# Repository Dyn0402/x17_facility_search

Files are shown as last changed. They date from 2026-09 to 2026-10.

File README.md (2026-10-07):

# x17_facility_search

Where else could the n_TOF X17 apparatus make an X17 measurement?

The MX17 setup (a ³He target, four arms of Micromegas TPCs, SiPM and plastic
trigger scintillators, and a DREAM readout) ran at CERN n_TOF in 2026 to look for
the X17 boson in n + ³He → ⁴He\* → ⁴He + e⁺e⁻. This repo asks which other neutron
facilities could host the same hardware, possibly with a new target and modest
upgrades, and how far each one could reach in X17/IPC.

The studies start analytic (Highland scattering budgets, rate scaling, published
beam data). Each one is then checked against Geant4 campaigns of the full
apparatus, run on lxplus/HTCondor.

## Facilities

| facility | beam | status | where |
|---|---|---|---|
| **ILL Grenoble, PF1B** (also FIPPS) | Continuous cold reactor beam, ~10¹⁰ absorbed n/s, thermal capture at rest (E\* = 20.58 MeV) | **Most developed.** Full Geant4 campaign done. One unpolarised 50-day cycle reaches X17/IPC(M1) ≈ 1.2×10⁻² at 3σ with n_TOF hardware, Micromegas-segment cuts and a CFRP end cap. That is ~7× short of ATOMKI's ⁸Be level, and ×3–4 short even with zero background. Current work: rate walls, flight tube, window choice, polarised option. | [`ill/`](ill/README.md) |
| **LNL Legnaro, AN2000 / CN** | DC ~1 MeV protons on a thin ⁷Li film, the ATOMKI reaction ⁷Li(p,e⁺e⁻)⁸Be at the 18.15 MeV resonance; up to 1 µA (AN2000) / ~4 µA (CN, also pulsed) | **Started 2026-10-07.** Facility, reaction and targets researched; pre-Geant4 estimate: the ATOMKI ratio at 3σ in ~2 weeks at 1 µA with the n_TOF hardware (~1 week with calorimetry), IPC-limited once the MM tracks veto cosmics. LNL's own ⁸Be spectrometer already ran there in 2023–24. Next: slides, Geant4 target region. | [`lnl/`](lnl/README.md) |
| **GANIL / SPIRAL-2 NFS** (Caen) | Pulsed fast neutrons, d+Be or quasi-monoenergetic, 1–40 MeV | Plan plus a literature beam reference. The open issue is the sub-2 MeV flux the physics wants: it is unmeasured. Options include a lower deuteron energy, D(d,n), and ⁷Li(p,n) near threshold. | [`docs/PLAN_GANIL_NFS.md`](docs/PLAN_GANIL_NFS.md), [`ganil_nfs/`](ganil_nfs/README.md) |
| FRM II MEPHISTO, ESS ANNI, NIST, HFIR | Cold beams | Mentioned only (`ill/FACILITY.md`, "Alternatives") | — |

## Layout

| directory | what it is |
|---|---|
| [`ill/`](ill/README.md) | ILL feasibility: facility record (`FACILITY.md`), analytic projection (`ill_rates.py`), the Geant4 answer (`FEASIBILITY_SIM.md`), polarised option (`POLARISED.md`), lxplus drivers (`sim/lxplus/`), slide deck (`deck/build_deck.py`) |
| [`lnl/`](lnl/README.md) | LNL feasibility for the ⁸Be search: facility (`FACILITY.md`), reaction (`PHYSICS.md`), lithium targets (`TARGETS.md`), the rate/acceptance/reach model (`lnl_rates.py` → `ESTIMATES.md`), and the Geant4 plan (`GEANT_PREP.md`) |
| [`ganil_nfs/`](ganil_nfs/README.md) | NFS beam reference: spectra, converters, timing, backgrounds, rates for our geometry, with sources (`refs/`) and a beam model (`nfs_beam.py`) |
| `docs/` | The GANIL/NFS plan and its anchor calculations (`anchor_kinematics.py`, `anchor_numbers.py`, `anchor_vessel.py`) |
| [`trigger_scint/`](trigger_scint/README.md) | Facility-independent: fixing the trigger-scintillator acceptance. The as-built stack accepts 2.3 % of X17 pairs; four ~75 cm plastics give ~14 %. Includes big-slab backgrounds at the ILL. |
| [`he4_bag/`](he4_bag/README.md) | A ⁴He bag / flight tube against air ¹⁴N, and the ³He-tight cell skin (12 µm PET + 6–7 µm Al) |
| `vessel_design/` | Parametric CAD of the 1 bar mylar-wrap, carbon-rod-cage ³He cell (STEP/STL/FreeCAD in `out/`) |
| `3he_material_budget/` | Early Highland material-budget script for the ³He target |
| `HANDOFF.md` | Running session handoffs, newest first: what is in flight on lxplus and the next steps |

## Running

Python 3 with numpy, pandas and matplotlib. The repo has no venv of its own; use
the nTof_x17 one:

```bash
~/PycharmProjects/nTof_x17/.venv/Scripts/python.exe ill/ill_rates.py --write   # Windows
~/PycharmProjects/nTof_x17/.venv/bin/python        ill/ill_rates.py --write   # Linux
```

Each subdirectory README lists its commands and outputs. Geant4 runs only on
lxplus (see `CLAUDE.md` for paths). The small analysis outputs are copied back
into `*/sim/` and `*/out/`; the full outputs stay on EOS.

## Related repositories

- **`MX17_Full_Geant`** (GitHub `Dyn0402/MX17_Full_Geant`, `~/CLionProjects/`):
  the full Geant4 simulation of the n_TOF apparatus. The `ill` and
  `trigger_plastics` branches carry the facility-search geometry.
- **`MX17_Geant`** (`~/CLionProjects/MX17_Geant`): the Micromegas module Geant4
  sim and the one shared module geometry (`shared/MX17ModuleGeometry.hh`).
- **`nTof_x17`** (`~/PycharmProjects/nTof_x17`): the n_TOF data analysis, the fast
  MC and the measured detector response.
- **`nTof_x17_DAQ`**: DREAM DAQ characterisation (dead time, rate limits).
- **`dylan-cern-site`**: publishes the notes and decks
  (`dylan-neff.web.cern.ch/notes/`).

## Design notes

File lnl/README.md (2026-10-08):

# LNL (Legnaro): the ATOMKI ⁸Be search with the MX17 apparatus

Started 2026-10-07. Could the n_TOF X17 apparatus repeat the ATOMKI measurement,
⁷Li(p,e⁺e⁻)⁸Be at the 18.15 MeV resonance, on a low-energy proton beam at INFN
Laboratori Nazionali di Legnaro? What is the beam, what does a lithium target look
like, and how far would we get before any Geant4?

## Read this first: the Geant4 result (2026-10-08, `FEASIBILITY_SIM.md`)

Days to show the ATOMKI ratio R = 5.8×10⁻⁶ at **3σ**, Li₂O 300 µg/cm² at 1.10 MeV, **1 µA**,
data-like selection on Geant4 L1–L6:

| hardware | counting / template fit | at CN 4 µA |
|---|---|---|
| **n_TOF as built** (LS read out), with 3° MM segments **or** a 0.3 ns TOF veto | **15 / 22 d** | 4 / 6 d |
| as built, LS dead | 19 / 25 d | 5 / 6 d |
| **4 big plastics 75×75×5 cm + all 20 SiPM bars** (trigger_scint, ~€90–140k) | **1.2 / 1.6 d** | **0.3 / 0.4 d** |

- **Signal acceptance as built: 3.3 % pair-tag** (2.4× below the toy × `EPS_REST`). The
  two 20×30 cm plastics are the bottleneck; the big plastics give 23 %.
- **E_sum separates the γ₁ (15 MeV) IPC.** It is removed as built (with LS) and with the
  big plastics; with the LS off it is not.
- **Cosmics are the one danger:**
  - 8×10⁴/day in 125–155° at trigger level, against ~120 IPC/day after cuts;
  - the measured chambers' 15° segments do not stop them;
  - an upper E_sum edge (muons leave 20–35 MeV), 3° segments or TOF do.
- EPC, accidentals, DREAM dead time, the 478 keV line: negligible.
- Keep the **CFRP chamber and a low-Z backing**. Al 1 mm doubles σ_θ (5° → 12°).
- The E0 6.05 MeV calibration line is invisible to the n_TOF trigger. Calibrate on 441 keV.

The pre-Geant4 estimate below is kept for the record. Its detector factors are superseded.

## Bottom line (pre-Geant4, good to ~×2; detector part superseded above)

- **The beam is easy.**
  - AN2000: 0.2–2 MV, up to 1 µA H⁺, self-service.
  - CN: 0.8–5.5 MV, 1 µA at 0.8–2 MeV in the beam sheet; ~4 µA authorised; also a
    3 MHz, < 2 ns **pulsed** mode.
  - Both cover 441–1225 keV. There are **no neutrons below the 1.88 MeV ⁷Li(p,n)
    threshold**, so radiation protection does not cap the current.
  - Access is through the LNL PAC (yearly, autumn) `FACILITY.md`.
- **LNL already did this.**
  - The LNL-INFN pair spectrometer (Marchi, Góngora-Servín, Tagnani *et al.*;
    ATOMKI-style plastic ΔE–E clovers) ran on **AN2000 in 2023–24**: LiF targets,
    441 keV and 1.03 MeV, ~800 nA, ~790 h.
  - It is still unpublished as of Oct 2026.
  - They are the first people to talk to.
- **The physics.**
  - A ~1 MeV proton is captured on ⁷Li, making ⁸Be\* at E\* = 17.255 + 0.875·E_p MeV.
  - It does so mostly via two M1 resonances (441 keV → 17.64; 1030 keV → 18.15),
    on top of a flat **E1 direct capture that is ~half of the γ₀ at 1.03–1.10 MeV**.
  - X17 pairs pile up above an edge at **~134–138°**.
  - Details in `PHYSICS.md`.
- **Who has looked so far.**
  - ATOMKI: 6.8σ in 2016; also off-resonance in 2022.
  - Hanoi: > 4σ in 2024.
  - **MEG II: nothing**, R(18.1) < 1.2×10⁻⁵ (2025).
  - MEG II members showed in **Sept 2026** that cosmic rays make a 140° bump in
    ATOMKI-type spectrometers.
- **Targets** (`TARGETS.md`).
  - A few-hundred-nm film of LiF or Li₂O (or Li metal, or sputtered LiPON) on a
    10–25 µm Al/C/Cu foil, in a thin carbon-fibre chamber.
  - Keep it thin (≲ 300 µg/cm² ≈ 60 keV), so the beam never slows into the 50×
    stronger 441 keV resonance. ATOMKI's 2016 metallic-Li targets did exactly that.
  - Use **boron-free** Li: ¹¹B(p,γ) puts 16–17 MeV γ in the window.
- **Rates.** At ATOMKI conditions (Li₂O 300 µg/cm², 1.10 MeV, 1 µA):
  - ~1.9×10³ γ₀/s and ~7 IPC/s into 4π;
  - **~900 X17/day** at the ATOMKI ratio R = 5.8×10⁻⁶.
- **Our apparatus.**
  - The four big Micromegas arms see the 140° region through opposite arms, at
    **~40 % geometric acceptance** (ATOMKI's spectrometer: ~2.5 %).
  - After the as-built trigger stack, ~46 X17/day are accepted at 1 µA, against
    ~1.1k (γ₀) + 2.1k (γ₁) IPC and ~200 cosmics per day in 125–155°.
- **Reach.** Days to show the ATOMKI ratio at **3σ / 5σ**, 1 µA:

  | stack | days, 3σ / 5σ |
  |---|---|
  | as built (cannot separate 15 from 18 MeV) | **~15 / ~40** |
  | with calorimetry | **~6 / ~16** |

  - ×4 faster at CN's 4 µA.
  - MEG II's 90 % limit is crossed in ~¼ of that time.
  - Off-resonance points (0.8, 1.225 MeV) are 3–4× slower.
  - Full table in `ESTIMATES.md`.
- **The MM tracking is the decisive advantage.**
  - With segment + collinearity cuts (ILL §10), cosmics drop below the IPC.
  - Without them the reach is 2.5× worse and cosmics dominate, which is the failure
    mode the 2026 paper attributes to ATOMKI.
  - CN's pulsed beam and the point-vertex cut add margin.
- **For comparison:** this is a much easier experiment for MX17 than the ILL thermal
  search (`../ill`). It has ~3× the accepted signal per day and no neutron
  backgrounds, and it is the measurement that decides the claim.

**Biggest unknowns, and what replaces them** (`GEANT_PREP.md`):
1. the trigger × E_sum × reconstruction factor carried from the ILL (`EPS_REST` = 0.14);
2. whether the stack can separate 15 MeV from 18 MeV pairs;
3. cosmics in the LNL hall;
4. hall space at AN2000/CN.

## Files

| file | what it is |
|---|---|
| `FACILITY.md` | LNL: AN2000 and CN specs, current/energy limits, pulsed beam, lines, schedule, PAC route and contacts, the local ⁸Be group, open questions **(ask)** |
| `PHYSICS.md` | The reaction step by step, ⁸Be levels and widths, direct capture, IPC, X17 kinematics vs E_p, every measurement so far (ATOMKI 2016/2022, Hanoi, MEG II, LNL, MEG-2026 cosmics), what a new measurement must get right |
| `TARGETS.md` | What a Li target is and how it is made; LiF vs Li₂O vs Li vs LiPON; contaminant reactions (¹⁹F, ¹¹B, ²⁷Al…); backings, heat, dose; recommendation |
| `ESTIMATES.md` | The pre-Geant4 numbers: 4π rates per configuration, toy acceptance, reach and days-to-significance, assumption table |
| `FEASIBILITY_SIM.md` | **The Geant4 result** (L1–L6, big plastics, 20-bar readout): acceptance, E_sum, cosmics, EPC, accidentals, DAQ, material, reach |
| `sim/lnl_geant.py` | The Geant4 analysis → `out/geant/` (tables + figures); `sim/fetch_sel.sh` copies the merged tables from EOS; `sim/lxplus/` = condor reduce/merge (`lnl_pipe.sh`) |
| `GEANT_PREP.md` | What to build in MX17_Full_Geant (branch `lnl` from `ill_ring`), the run list L0–L6, decisions needed first |
| `lnl_rates.py` | The model: kinematics, Zahnow σ split into resonances + direct capture, PSTAR stopping, thin/thick yields, Born IPC (from nTof_x17 `ipc_born`), four-arm toy acceptance, counting reach |
| `out/*.csv`, `out/figures/` | `kinematics`, `excitation`, `yields`, `ipc_alpha`, `acceptance(_hist)`, `reach`; figures with their CSVs; `viewer_yield_grid.json` (the `Y` table in the 3D viewer) |
| `data/exfor_A0639_Zahnow1995.txt` | ⁷Li(p,γ)⁸Be S-factors, γ₀ and γ₀+γ₁, 98–1500 keV (EXFOR) |
| `data/pstar_stopping.csv` | NIST PSTAR proton stopping for LiF, Teflon, C, O, Al, Be, Cu, Ti, Mo, W, Au, Ag, Kapton, Mylar, air, H |
| `viz/lnl_setup_3d.html` | 3D view to scale: MX17 arms + trigger stack around the Li target and chamber, vs the LNL 2023–24 clovers and ATOMKI 2016; live rates per machine/energy/film from `lnl_rates.py`; illustrative X17 / IPC / cosmic events |
| `refs/*.txt` | Text extractions of every source (PDFs in `refs/pdf/`, not committed) |

```bash
PY=~/PycharmProjects/nTof_x17/.venv/Scripts/python.exe   # Linux: .venv/bin/python
$PY lnl/lnl_rates.py          # tables + CHECK lines + figures (~3 min)
$PY lnl/lnl_rates.py --quick  # tables only, small MC
```

`lnl_rates.py` imports `sept26_prelim_analysis/ipc_born.py` from the nTof_x17 checkout
(`$NTOF_X17`, default `~/PycharmProjects/nTof_x17`). The CHECK lines compare it with
Tilley (σ at 441 keV, branching), Rose (IPC α), MEG II's own normalisation, and a
measured thick-target yield.

## Status and next steps (2026-10-08)

1. **Slides: done.** `deck/build_deck.py` → `out/lnl-x17-feasibility.html`, live at
   dylan-neff.web.cern.ch/notes/lnl-x17-feasibility.html and linked from `/facilities/lnl.html`.
   Rebuild after any change to `lnl_rates.py` outputs, then republish with `add-note.py … --force --deploy`.
   Slides 15–33 are a "basics" appendix (beam, targets, chamber, the physics channel incl. where the
   beam energy goes (E*, C1a–c), glossary),
   built by `deck/appendix.py` from `appendix_calc.py` → `out/appendix/*.csv` (2026-10-08). Its
   chamber-wall resolutions other than the three Geant4 walls are a Highland model fitted to L5
   (an analytic stand-in).
2. **Geant4: done** (2026-10-08), `FEASIBILITY_SIM.md`. Open: the SiPM-wall time
   resolution and whether the LS can be read (ask); the Zhang–Miller IPC shapes.
3. **Emails** (not sent). Anna Selva / pacbeams@lnl.infn.it (machines, hall, next PAC);
   T. Marchi (their 2023–24 data, the Góngora-Servín thesis, collaboration); our own
   collaboration (the ATOMKI demonstrator test).

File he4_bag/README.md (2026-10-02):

# A ⁴He bag around the ILL ³He target

2026-10-02. The question: air ¹⁴N is a significant background at the ILL
(`../ill/`). Would a ⁴He balloon around the ³He cell remove it? What would it
do to lepton scattering and to ³He loss through the cell wall?

It also covers the follow-up: the ³He leak rate turned out to be large, so
how do we make the cell tight without adding background or e⁺e⁻ scattering,
and should it stay at 1 bar?

Everything here is analytic. It is calibrated against the ILL Geant4 campaign
where that campaign has a number: the ¹⁴N(n,γ) rate on the air path matches
V0 to 1 %.

| file | what it is |
|---|---|
| `he4_bag.py` | All the arithmetic. §1 neutrons in air vs ⁴He; §2 Highland scattering on the cell → Micromegas chord; §3 ³He permeation of G1–G6, in air or in a ⁴He bag; §4 alternative skins for the 1 bar cell; §5 leak budget of seals and bonds; §6 choosing the foil (metal, gauge, scattering budget, strength) |
| `make_he4_bag_deck.py` | The slide note, built with `dylan-cern-site/scripts/slidedoc.py`. It reads `he4_bag.py` directly, so its numbers and titles follow the model |
| `out/neutrons.csv` | Captures and scattering per beam neutron on the 30 cm path, for air and for He at several air fractions |
| `out/leptons.csv` | θ₀ per leg vs lepton KE: air, ⁴He, ⁴He + bag foil |
| `out/permeation_bif{1,10}.csv` | Per cell: ³He loss per day and per cycle, cost, τ, ⁴He and air inflow, sealed-cell dilution |
| `out/he4_flush_bif1.csv` | Fresh-³He flow that holds ⁴He < 5 % in a cell sitting in the bag |
| `out/skins.csv` | Skin options for the G1 geometry: x/X₀, θ₀ at 6.3 MeV, loss range, barrel captures, hardest γ line |
| `out/seals.csv` | Leak budget: O-rings, epoxy bonds, foil pinholes, bare barrel |
| `out/metals.csv` | §6a: barrier metals (Al, Be, Mg, Zr, Cu, Pb) at their thinnest foil on 12 µm PET |
| `out/foil_gauge.csv` | §6b: Al gauge 6–25 µm: θ₀, captures, typical pinholes, barrel loss |
| `out/chord_budget.csv`, `out/chord_ladder.csv` | §6c: x/X₀ per layer of a lepton leg; θ₀ as the big layers are replaced |
| `out/hoop.csv` | §6d: membrane stress at 10 / 30 / 50 / 1000 mbar |
| `out/figures/he4_bag.png` (+ `.csv`) | Summary figure: ¹⁴N vs bag purity, and the sealed-cell ³He decay |
| `out/he4_bag_deck.html` | The slide note, live at <https://dylan-neff.web.cern.ch/notes/ill-he4-bag-3he-leak.html> |

```bash
python3 he4_bag/he4_bag.py              # tables -> he4_bag/out/
python3 he4_bag/make_he4_bag_deck.py    # -> he4_bag/out/he4_bag_deck.html
python3 ~/PycharmProjects/dylan-cern-site/scripts/add-note.py he4_bag/out/he4_bag_deck.html \
        --slug ill-he4-bag-3he-leak --force --deploy
```

Inputs from `../ill/`:
- `out/h113_spectrum.csv`;
- the V0 and C1 rates quoted in `SIM_STATUS.md` and `FEASIBILITY_SIM.md`;
- `sim/analysis_v3/contract_ladders.csv` (wall captures).

It needs numpy, pandas, scipy and matplotlib. The figure uses
`ill/figstyle.py`.

**Assumptions to replace with measurements:**
- He permeability: PET ~1 barrer (literature, ~2×); Kapton 1 barrer
  (placeholder, sources differ ~10×). N₂ 0.006 and O₂ 0.03 barrer in PET.
- ³He permeates 10 % faster than ⁴He.
- Metallisation barrier factor (BIF): 1–10, unmeasured.
- Foil pinholes: ~50/m² at 9 µm.
- Viton O-rings: Parker rule, 9 barrer. Epoxy: 5 barrer.
- ³He at 2500 €/L(STP).
- ~10⁻⁴ barrel crossings per beam neutron.

## Bottom line

- **⁴He gives no ¹⁴N-like background.** It captures no neutrons at all,
  because there is no bound ⁵He. It also scatters neutrons ~13× less than air.
- **The air that matters is the 300 mm of open beam path** between the
  collimator aperture and the Be window, not the air around the cell.
  - The analytic ¹⁴N(n,γ) rate on that path is 2.54 × 10⁻⁴ per beam neutron.
    Geant4 V0 gives 2.5 × 10⁻⁴ (ratio 1.01).
  - All air in C1 gives 2.7 × 10⁻⁴/n. So ~90 % of the ¹⁴N(n,γ) is the
    direct beam in that path. The other ~10 % is scattered neutrons captured
    in air around the detector. (This split is inferred by comparing two runs;
    it was not tallied directly.)
- **So the sensible version of the idea is a He-filled (or evacuated) flight
  tube** from the aperture to the Be window, sealed onto the cell flange. It
  removes:
  - ~90 % of the air ¹⁴N(n,γ);
  - the 0.6 % ¹⁴N(n,p) loss;
  - the ~2 % of beam scattered in air.

  The He only has to be ~99 % clean: the remaining ¹⁴N scales with the air
  fraction (1 % air → 2.5 × 10⁻⁶/n, a 100× reduction). This is standard
  beamline practice and was already on the list in `FEASIBILITY_SIM.md` §6.4.
- **A balloon around the cell and detector is not worth it.**
  - What it would add: the remaining ~10 % of air captures, and ~20 % less
    lepton scattering, which is worth < 2 % in reach.
  - What it would cost: it floods a mylar cell with ⁴He (see below). He would
    also permeate the Micromegas entrance windows into their gas, and HV breaks
    down far more easily in He than in air.
- **Permeation: the bag neither slows nor speeds the ³He loss**, because the
  ³He partial pressure outside is ~0 in air and in ⁴He alike. **It does hurt
  through what comes in.** ⁴He enters the cell ~90× faster than N₂ + O₂ do
  from air (mylar), or ~20× faster (Kapton). A sealed cell in the bag slowly
  becomes ⁴He.
- **Side finding that matters more:** bare 12 µm mylar (G1) loses ~0.45 L(STP)
  of ³He per day. That is a 3.4-day time constant, ~22 L per 50-day cycle, of
  order 50 k€. The source figure is a literature PET He permeability of
  ~1 barrer, uncertain by ~2×. Either the metallisation gives a measured ≳10×
  barrier, or G1 needs a feed system and a budget for the loss. This sharpens
  the "G1 if permeation is manageable" caveat in `FEASIBILITY_SIM.md` §5.

## 1. Neutrons (H113 beam, mean λ 4.87 Å)

Cross sections: thermal values (Sears/NIST), scaled as 1/v for absorption. The
free-gas correction is applied for scattering.

| gas on the 30 cm path | ¹⁴N(n,γ) 10.8 MeV /n | ¹⁴N(n,p) /n | ⁴⁰Ar(n,γ) /n | scattered |
|---|---|---|---|---|
| air | 2.5e-4 | 5.8e-3 | 1.3e-5 | 1.6 % (G4: ~2 %) |
| He + 5 % air | 1.3e-5 | 2.9e-4 | 6e-7 | 0.19 % |
| He + 1 % air | 2.5e-6 | 5.8e-5 | 1e-7 | 0.13 % |
| pure ⁴He | 0 | 0 | 0 | 0.12 % |

- With the air path in He, the hardest remaining single-capture lines near the
  beam come from the Be window (1.4 × 10⁻⁴/n, 6.8 MeV) and the Al ring
  (1.5–1.9 × 10⁻⁴/n, 7.7 MeV). Both are well below the Esum > 13 MeV cut.
  - ¹⁴N survives in the Kapton walls (G3–G6) and in the air around the
    detector, so the 10.83 MeV endpoint does not go away. Its rate drops ~10×.
- Use mylar, not Kapton, for any tube window: Kapton contains N.
- The 2 % of the beam scattered in air may also feed some of the captures in
  the detector materials (~1 × 10⁻³/n), which dominate the Micromegas rate.
  Analytics cannot settle that. **One Geant4 rerun would:** C1 on G1 with the
  flight path set to G4_He. It would also give the change in Micromegas rate
  and in the accidental Esum tail.

## 2. Lepton scattering

Highland θ₀ per leg, for the G1 skin, the Micromegas entrance and 16 cm of
gas. The energies are the p10/50/90 of the softer X17 lepton and the median of
the harder one.

| KE [MeV] | air | ⁴He, bag sealed on the MM windows | ⁴He + 25 µm mylar foil | ⁴He + 100 µm foil |
|---|---|---|---|---|
| 4.1 | 5.0° | 4.0° | 4.2° | 4.7° |
| 6.3 | 3.4° | 2.7° | 2.8° | 3.2° |
| 9.1 | 2.4° | 1.9° | 2.0° | 2.3° |

- ⁴He reduces the scattering by ~20 %, as long as the bag foil is thin.
- The reach does not care. The opening-angle resolution is set by the
  assumed-vertex term (7.8° against 2.2° with the true vertex), and even ideal
  vertexing gains only 13 % (`FEASIBILITY_SIM.md` §1).

## 3. ³He permeation (Fick's law per species, barrel area only)

The model:
- Mylar: He 1 barrer, N₂ 0.006, O₂ 0.03.
- Kapton: He 1 barrer, a placeholder; sources disagree by 10×.
- ³He permeates 10 % faster than ⁴He (assumed).
- BIF is the barrier improvement factor of a metallisation; it is unmeasured.

| cell | ³He fill [bar·L] | loss, bare [L/day] | per cycle, bare | τ bare | τ BIF 10 | ³He left after 50 d sealed in the bag (bare / BIF 10) |
|---|---|---|---|---|---|---|
| G1 1 bar mylar R40 | 1.5 | 0.45 | 22 L (~56 k€) | 3.4 d | 34 d | 0 % / 23 % |
| G2 1 bar mylar R100 | 9.4 | 1.1 | 56 L | 8.4 d | 84 d | 0 % / 55 % |
| G3 2 bar Kapton R40 | 1.5 | 0.049 | 2.4 L | 31 d | 310 d | 20 % / 85 % |
| G5 3 bar Kapton R40 | 1.5 | 0.023 | 1.2 L | 65 d | 650 d | 46 % / 93 % |

What the bag changes:

- **³He out: unchanged.** It is driven by the ³He partial pressure, which is
  ~0 outside in either case.
- **What comes in.**
  - In air: N₂ + O₂ at 1/90 of the ³He loss rate (mylar). Over a sealed cycle
    that makes ~6 % N₂ in G1. That causes 2 × 10⁻⁶/n of in-cell ¹⁴N(n,γ),
    which is negligible.
  - In ⁴He: ⁴He at ~the ³He loss rate.
    - For the zero-Δp mylar cell this keeps the pressure balanced; in air the
      cell would collapse instead. But it dilutes the ³He, and the stopping
      length grows as 1/p(³He).
    - Holding ⁴He < 5 % in G1 needs ~8 L/day of fresh ³He flushed through
      (5 cell volumes a day). The outflow is a ³He/⁴He mix that can be reused
      only after isotope separation. For the Kapton cells it is 0.1–0.4 L/day.
- **The one upside:** permeated ³He goes into the bag instead of the hall. At
  < 1 % concentration in a flowing bag, though, it is not practically
  recoverable.

## 4. Stopping the leak without adding material (`he4_bag.py` §4–5)

- **Pressure doesn't make a cell tighter.** Permeation follows the ³He partial
  pressure. A pressure wall needs t = Δp·R/σ. At a fixed bar·L inventory, the
  loss goes as 1/(p − 1) and x/X₀ goes as (p − 1). So every polymer wall sits
  on the same loss × x/X₀ line, and so does bare PET at any thickness.
- **So stay at 1 bar, and make the skin a barrier rather than a wall.** Rolled
  Al foil is impermeable to He: gas gets through only at pinholes, of which a
  9 µm foil has ~50/m².
  - A 12 µm PET + 9 µm Al laminate is 1.4 × 10⁻⁴ X₀.
  - It raises θ₀ at 6.3 MeV by +4 % (3.37° → 3.49°).
  - Its barrel captures are ~10⁻⁸/n (Al lines ≤ 7.7 MeV), against
    3.8 × 10⁻⁴/n for the other cell solids.
  - The barrel loss is < 10⁻⁴ L per cycle, even with 100× more pinholes from
    creasing on the rods.
- **The leak then moves to the seals.** The Viton O-rings (Be window, Al cap)
  pass ~8 cm³ per cycle; the epoxy bonds pass ~10⁻⁵ L. Indium or metal seals
  would go lower.
- **This can be tested on the bench.** Bare G1 leaks ~5 × 10⁻³ mbar·L/s; a
  foil cell should leak ~2 × 10⁻⁶. A standard He leak detector reaches 10⁻¹⁰.
- Vapour-deposited Al (the existing 2 × 40 nm on the mylar) is not the same
  thing. Its He barrier factor is unmeasured and probably a few.

Slide note: `make_he4_bag_deck.py` → `out/he4_bag_deck.html`, published at
<https://dylan-neff.web.cern.ch/notes/ill-he4-bag-3he-leak.html>.

## 6. Choosing the foil (`he4_bag.py` §6, follow-up 2026-10-02)

Four questions. Is there a barrier better than Al that doesn't capture
neutrons? How thin can the foil go? What dominates the scattering, if not the
foil? Does a 1 bar cell need any strength?

**The foil is already outside the beam.** The beam at the window is
r50/90/99 = 7.1 / 10.2 / 12.9 mm (Geant4 V0), and the G1 barrel sits at
R = 40 mm. Only neutrons scattered in the ³He reach it, ~10⁻⁴ per beam
neutron, so a 12 µm PET + 7 µm Al skin gives ~1.3 × 10⁻⁸ captures/n. The
other sources are far larger:
- Be window: 1.4 × 10⁻⁴/n.
- Al ring and caps: 1.5–1.9 × 10⁻⁴/n.
- 30 cm air path: 2.5 × 10⁻⁴/n.

The Al that matters is the **8 mm end caps**. The upstream cap and ring are in
63 % of G1 accidentals (`../ill/FEASIBILITY_SIM.md` §9). Two Geant4 runs would
settle it:
1. C1 on G1 with the laminate skin. This needs a two-layer `--skin`;
   `Al:0.007` alone gives a bound.
2. G1 with the upstream cap lined with ⁶LiF, or trimmed, run through
   `acc_sources.py`.

**Aluminium is the right metal.** Each option below is at its thinnest
metre-size foil, laminated on 12 µm PET:

| metal | thinnest foil | capture/µm vs Al | X₀/µm vs Al | θ₀ 6.3 MeV | hardest γ | verdict |
|---|---|---|---|---|---|---|
| Al | 6 µm | 1 | 1 | 3.45° | 7.72 | use |
| Be | 8 µm | 0.07 | 0.25 | 3.40° | 6.81 | small brittle toxic discs, can't be wrapped |
| Mg | 25 µm | 0.19 | 0.62 | 3.58° | **11.09** | ²⁵Mg line above ¹⁴N |
| Zr | 10 µm | 0.57 | 5.7 | 4.09° | 8.63 | ×6 scattering |
| Cu | 6 µm | 23 | 6.2 | 3.85° | 7.92 | ×23 capture |
| Pb | 25 µm | 0.41 | 16 | 7.16° | 7.37 | ×16 scattering |

- Polymers and coatings are not He barriers: they gain ≲10×, against ≳10⁴×
  for a continuous metal foil. That covers vapour Al, AlOx/SiOx, EVOH and LCP.
- The choice of metal barely matters anyway. With Al, half of the barrel's
  ~10⁻⁸/n comes from the PET's hydrogen.

**Gauge: 6–7 µm converter foil.**
- Pinholes only matter at ~1.5 × 10⁶ per m², about one per mm². Only above
  that does the barrel reach the O-ring floor of 8 cm³ per cycle.
- Typical 6 µm foil has ~10³ per m². Even with ×100 more from creasing, the
  barrel stays ~15× under the floor.
- θ₀ at 6.3 MeV is 3.45° with 6 µm, 3.49° with 9 µm and 3.70° with 25 µm.
- **Order PET/Al only.** Stock packaging laminates add a 50–100 µm PE
  heat-seal layer, which has more X₀ than everything else in the skin.

**The scattering "base" is the detector, not the cell.** Share of x/X₀ on one
lepton leg:

| layer | share |
|---|---|
| Micromegas entrance, 9 µm Cu | 39 % |
| 16 cm air, cell → Micromegas | 33 % |
| Micromegas entrance, 50 µm Kapton | 11 % |
| Micromegas entrance, 40 µm mylar | 9 % |
| 7 µm Al foil | 5 % |
| 12 µm PET | 3 % |

θ₀ at 6.3 MeV for each configuration:

| configuration | θ₀ |
|---|---|
| no skin | 3.32° |
| 12 µm PET (G1 as simulated) | 3.37° |
| 12 µm PET + 7 µm Al | 3.46° |
| …and an aluminised Micromegas cathode instead of the 9 µm Cu | 2.63° |
| …and He on the 16 cm chord | 1.76° |

- The cathode is the cheap win. The 9 µm Cu is assumed to be the drift
  cathode's cladding; check that against the detector drawings.
- **Scattering does not set the reach.** The opening-angle resolution is 7.8°,
  dominated by the assumed vertex (§2).

**Strength at 1 bar: little, but not none.** At R = 40 mm the membrane
stress is σ = Δp·R/t:

| case | laminate | 7 µm Al alone |
|---|---|---|
| 50 mbar (±30 mbar weather + a few K on a sealed cell) | 11 MPa | 29 MPa |
| yield | PET ~100 MPa | soft Al foil ~35 MPa |

- Keep the PET as the load layer. Dropping it saves only ~1 % in θ₀.
- **The cell can't be pumped out to fill it.** A full 1 bar inward collapses
  the skin between the rods. Pump it down inside a vacuum enclosure, or
  flush-fill it, which wastes ³He.
- A bellows or a small reservoir on the fill line would hold Δp near 0.

Assumptions:
- The pinhole densities, thinnest foils and yields are catalogue-level, good
  to an order of magnitude.
- The barrel crossing rate is analytic.

## Verdict

The idea makes sense in a narrower form: **put the beam's air path in He (or
vacuum), not the target.** It is cheap, standard, and removes ~90 % of the
¹⁴N(n,γ), with an analytic rate that matches Geant4. Surrounding the cell
itself buys almost nothing more. It makes the permeation problem worse for the
mylar cell and adds He problems for the Micromegas and HV. The more urgent
item is G1's own ³He permeation. Stay at 1 bar, but use a rolled-Al-foil
laminate skin: 12 µm PET + 6–7 µm Al converter foil, with no PE sealant layer.
Fill it inside a vacuum enclosure, and leak-test a prototype before the design
freeze. The foil is outside the beam. The Al that drives the accidentals is
the 8 mm end caps, so line or trim those.

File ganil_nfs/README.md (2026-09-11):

# GANIL / SPIRAL-2 — Neutrons For Science (NFS): beam reference

**Compiled:** 2026-09-10 · for the X17 facility-search study (`docs/PLAN_GANIL_NFS.md`, Part 5)

Everything I could find in the open literature on the NFS neutron beam, tabulated
so a simulation can be built against it. Each number carries its source and the
conditions it was measured under. Where a number is a *model* rather than a
measurement, it says so.

**Read §7 first if you only care about the go/no-go.** The physics wants
E_n ≲ 2 MeV, and that is precisely the part of the NFS spectrum that has never
been measured.

Contents:

- [1. Facility at a glance](#1-facility-at-a-glance)
- [2. Primary beam](#2-primary-beam)
- [3. Converters](#3-converters)
- [4. Collimation, geometry, beam profile](#4-collimation-geometry-and-beam-profile)
- [5. Neutron spectra](#5-neutron-spectra)
- [6. Time structure, TOF, resolution](#6-time-structure-tof-and-energy-resolution)
- [7. The sub-2-MeV problem](#7-the-sub-2-mev-problem-and-the-alternatives)
- [8. Backgrounds](#8-backgrounds)
- [9. Rates for our geometry](#9-rates-for-our-geometry)
- [10. What the literature does not pin down](#10-what-the-literature-does-not-pin-down)
- [11. Files and sources](#11-files-in-this-directory)

---

## 1. Facility at a glance

| quantity | value | source |
|---|---|---|
| Location | GANIL, Caen; SPIRAL-2 experimental area, 9.5 m below grade | L21 |
| Converter room → TOF hall wall | 3 m concrete, pierced by the collimator | L21, P25 |
| TOF hall | 28 m long × 6 m wide (GANIL's own page says 30 m) | P25, G24 |
| Usable flight paths | 5 – 30 m; several experiments can run simultaneously along it | L21 |
| Neutron energy range | ~1 (design goal 0.1) – 40 MeV continuous; 5 – 30 MeV quasi-monoenergetic | L21, G24 |
| First neutron beam | September 2020; scientific exploitation from 2021 | I24 |
| Scientific coordinator | X. Ledoux (xavier.ledoux@ganil.fr) | G24 |
| Auxiliary | irradiation station in the converter cave + pneumatic transfer (45 s), HPGe in TOF hall, FASTER DAQ | L21 |

Note the 28 vs 30 m discrepancy: the refereed papers (L21, P25) both say 28 m;
GANIL's web page and outreach material say 30 m. Use 28 m.

---

## 2. Primary beam

| quantity | value | source |
|---|---|---|
| Accelerator | SPIRAL-2 superconducting LINAC, 26 cavities | L21 |
| RF frequency | 88 MHz (bunch spacing 11.4 ns) | L21 |
| Protons | 0.75 – 33 MeV (design 40 MeV) | G24, L21 |
| Deuterons | 0.75 MeV/u – 20 MeV/u, i.e. 1.5 – 40 MeV | G24 |
| Alphas / heavy ions | 0.75 – 20 MeV/u / up to 14 MeV/u | G24, L21 |
| LINAC max current | 5 mA CW (3.12×10¹⁶ p or d/s) | L21 |
| Max current at NFS | **50 µA** = 3.12×10¹⁴ /s, set by the bunch selector and by radioprotection/thermal limits for 40 MeV d + 8 mm Be | L21 |
| Bunch selector | 1 bunch in N, downstream of the RFQ; N ≥ 100 required at NFS, hardware supports 10 < N < 10 000 | L21, S20 |
| Bunch selector mechanism | static dipole deflects onto a 7.3 kW scraper; two HV travelling-wave pulses (≤2.5 kV, ≤6 ns rise) keep the selected bunch on axis | S20 |
| Bunch width | design target 0.5 ns FWHM, 1 ns the accepted upper limit; measured shorter than the 80 ps electronic resolution | S20, L21 |
| Achievable repetition rates | 8.8 kHz – 8.8 MHz; **rates actually run: 22 kHz, 440 kHz, ~1 MHz** | L21, P25, M25 |

⚠ **Inconsistency in L21.** The commissioning paper states "the beam frequency was
set to 22 kHz (N=400)". 88 MHz / 400 = 220 kHz, not 22 kHz — one of the two is a
typo. The 2025 PS-PPAC campaign unambiguously used 440 kHz (N = 200), and Medley
used ≈1 MHz. `docs/PLAN_GANIL_NFS.md` §5.2/§5.4 currently quotes "22 kHz,
45 µs period" as *the* NFS rate; that is one historical setting at most and
should be replaced by the table in §6 below — the choice of rate is ours to make
and it is the single most important beam parameter for us (see §6.2).

---

## 3. Converters

Three converters on a water-cooled holder; the two thin ones sit 40.8 cm
downstream of the rotating one.

| converter | spec | use | source |
|---|---|---|---|
| Thick ⁹Be, rotating | 8 mm thick, 170 mm diameter, 2000 rpm, sustains 2 kW | **continuous white spectrum**, d + Be | L21, G24 |
| Thin ⁹Be, fixed | 0.5 mm (1–3 mm range quoted elsewhere) | quasi-monoenergetic p + Be | L21, G24 |
| Thin ⁷Li, fixed | 1.5 mm | quasi-monoenergetic ⁷Li(p,n)⁷Be | L21 |

Derived / cross-checked:

| quantity | value | note |
|---|---|---|
| Range of 40 MeV d in Be | **5.6 mm** (this repo, Bethe CSDA) | 8 mm converter fully stops the beam |
| Range of 31.9 MeV p in Be | 6.45 mm (L21) | same conclusion |
| Deuteron transmission through the thick target | ~85–90 % survive as beam-like (only ~10–15 % react) | M23 Fig. 4 |
| Energy loss, 31.9 MeV p in 1.5 mm Li / 0.5 mm Be | 1.24 / 1.37 MeV | L21 — sets the QME peak width |
| Max current, thin Li / thin Be | 20 / 50 µA (melting points 180 / 1287 °C) | L21 |

---

## 4. Collimation, geometry and beam profile

| quantity | value | source |
|---|---|---|
| Collimator | inside the 3 m wall, conical bore, layered concrete / borated polyethylene / iron / lead | L21 |
| Collimator aperture used in 2025 | **25.55 mm diameter** | P25 |
| Angular aperture | 3.8×10⁻³ rad | L21 |
| Collimator exit → converter | **435.3 cm** (derived: 740.6 − 305.3) | P25 |
| Spot radius at collimator exit | ~1.7 cm | L21 |
| Spot radius at far end of hall (28 m) | ~13 cm | L21 |
| Second collimator, mid-hall | reduces spot radius back to ~2 cm | L21, I24 |
| Measured spot diameter at 740.6 cm | **44.4 ± 0.4 mm** | P25 |
| Measured 10–90 % edge fall-off | **4.9 ± 0.4 mm** | P25 |
| Measured divergence (half-angle) | **3.08 ± 0.07 mrad** | P25 |
| Beam solid angle at 740.6 cm | (28.2 ± 0.5)×10⁻⁶ sr | P25 |

**The converter behaves as a point source.** Projecting the 25.55 mm aperture
from a point at the converter through the measured geometry gives 43.5 mm at
740.6 cm against 44.4 ± 0.4 mm measured — 2 % — so a simple pinhole projection is
good enough for a simulation. `nfs_beam.beam_diameter_cm()` implements it:

| distance from converter | spot diameter (25.55 mm collimator) | on-axis flux vs 5 m |
|---|---|---|
| 5 m | 2.9 cm | 1.00 |
| 7.41 m (2025 PPAC position) | 4.4 cm | 0.46 |
| 10 m | 5.9 cm | 0.25 |
| 13.6 m | 8.0 cm | 0.14 |
| 20 m | 11.7 cm | 0.063 |
| 28 m | 16.4 cm | 0.032 |

The 8 cm spot the cell design is aimed at (`PLAN` §4.1) sits at **≈13.6 m** with
the 25.55 mm collimator — or much closer with a wider aperture, if one exists.
This is question Q1 in §10.

The sharp 4.9 mm edge is worth emphasising: the beam is essentially a flat-top
cylinder with a ~1 cm penumbra, so a 40 cm long cell is uniformly illuminated
along the axis and cleanly bounded transversely. For a simulation, a uniform
disc convolved with a ~2 mm σ Gaussian reproduces the measured profile.

---

## 5. Neutron spectra

### 5.1 d(40 MeV) + thick Be — the workhorse

This is the reference reaction and the one to simulate. The only published
*absolute, differential* measurement of the NFS beam itself is P25.

| quantity | value | source |
|---|---|---|
| Spectrum shape | continuous, broad breakup bump | P25 |
| **Peak** | **(17.3 ± 0.5)×10⁹ n/µC/sr/MeV at E_n = 17 MeV** | P25 |
| Above 10⁹ n/µC/sr/MeV | 1.5 – 35 MeV | P25 |
| Above 10⁸ n/µC/sr/MeV | 1.5 – 42 MeV | P25 |
| Reported range | 1.5 – 44 MeV; **non-zero above the 40 MeV beam energy** (positive-Q channels) | P25 |
| Mean energy at 0° | ≈14 MeV | G24, L21 |
| Total 4π yield | 1.8×10¹³ n/s at 50 µA = **0.058 n per deuteron** | L21 |
| Flux near the converter | ~10¹¹ n/cm²/s (2×10¹⁰ per GANIL's page) | L21, G24 |
| Average flux, TOF hall, short flight path | ~10⁸ n/cm²/s, peaking at 5×10⁶ n/cm²/MeV/s near 14 MeV, at 50 µA | L21 |
| Independent cross-check | Medley (H(n,p) recoil telescopes, ≈5 m) agrees with the PS-PPAC flux over **2 – 25 MeV** | M25 |

Measured constraints are collected machine-readably in
[`data/nfs_measured_anchors.csv`](data/nfs_measured_anchors.csv).

### 5.2 A spectrum you can actually evaluate

No one publishes the NFS spectrum as a table. To get a usable differential
source I implemented the **Serber-hybrid thick-target parameterisation** of
Morrell & Bernstein (PRC 108, 024616 (2023); M23) in
[`nfs_beam.py`](nfs_beam.py) and renormalised it to the measured 17 MeV peak.
M23 is the right choice here because it was fitted to exactly this data — thick
Be targets from 16–50 MeV including Saltmarsh's d(40 MeV)+Be, which P25 shows
agrees with the NFS beam.

Model components (all with recommended parameters, c₁…c₆ = 1):

| component | σ(ε_d) [mb] | E distribution | angular distribution |
|---|---|---|---|
| Breakup (stripping) | 57.2 (A^⅓+2^⅓) / (1+e^((22.3−ε_d)/9.4)) | Serber, centred at ½(ε_d−E_c), width w_d = 0.37 E_B = 0.823 MeV | Serber, θ₀ = 0.72 √(E_B/(ε_d−E_c))(1−ε_d/8m_dc²) |
| Compound | 80.6 [e^(−½((18−ε_d)/14)²) + 0.3/(1+e^((18−ε_d)/7))] | Watt, kT = 0.1 + 0.27√(ε_d+Q) | Kalbach–Mann with a → 1.1a |
| Pre-equilibrium | 34.2 / (1+e^((22−ε_d)/6)) | Watt, kT = 0.75 + 0.63√(ε_d+Q) | Kalbach–Mann with a → 1.8a |

with E_B = 2.225 MeV, Q = 4.36 MeV, E_c = 1.38 MeV for Be. Thick-target yield is
the integral over the deuteron slowing-down weighted by the transmission factor
τ (M23 Eq. 16). My τ = 0.95 over the full slowing-down; M23's Fig. 4 implies
~0.86 at 40 MeV, so my σ_T is somewhat low. A ≤10 % effect, absorbed entirely by
the renormalisation below.

**θ₀ = 9.9° at ε_d = 40 MeV.** Our collimator subtends 3.08 mrad = 0.18°, so the
beam is carved out of the flat top of the emission cone — the angular
distribution is constant to <0.1 % across the beam and can be ignored entirely
in a simulation. Only the 0° spectrum matters.

Output, renormalised (**model → data factor 1.293**, i.e. the parameterisation
is 23 % low in absolute terms), in
[`data/nfs_dbe40_0deg_model.csv`](data/nfs_dbe40_0deg_model.csv):

| E_n [MeV] | total | breakup | compound | pre-eq | breakup fraction |
|---|---|---|---|---|---|
| 0.1 | 1.32e9 | 9.87e8 | 3.20e8 | 1.04e7 | 0.75 |
| 0.2 | 1.46e9 | 1.01e9 | 4.36e8 | 1.50e7 | 0.69 |
| 0.5 | 1.74e9 | 1.10e9 | 6.14e8 | 2.46e7 | 0.63 |
| 1.0 | 2.01e9 | 1.25e9 | 7.15e8 | 3.70e7 | 0.63 |
| 1.5 | 2.20e9 | 1.44e9 | 7.20e8 | 4.77e7 | 0.65 |
| 2.0 | 2.38e9 | 1.64e9 | 6.82e8 | 5.76e7 | 0.69 |
| 3.0 | 2.79e9 | 2.15e9 | 5.59e8 | 7.56e7 | 0.77 |
| 5.0 | 4.03e9 | 3.60e9 | 3.23e8 | 1.07e8 | 0.89 |
| 8.0 | 7.29e9 | 7.02e9 | 1.22e8 | 1.44e8 | 0.96 |
| 10.0 | 1.03e10 | 1.01e10 | 6.11e7 | 1.63e8 | 0.98 |
| 14.0 | 1.65e10 | 1.63e10 | 1.46e7 | 1.83e8 | 0.99 |
| **17.0** | **1.73e10** | 1.71e10 | 4.91e6 | 1.86e8 | 0.99 |
| 20.0 | 1.20e10 | 1.18e10 | 1.63e6 | 1.79e8 | 0.98 |
| 25.0 | 3.50e9 | 3.35e9 | 2.49e5 | 1.50e8 | 0.96 |
| 30.0 | 1.17e9 | 1.07e9 | 3.47e4 | 1.04e8 | 0.91 |
| 35.0 | 4.96e8 | 4.46e8 | 3.70e3 | 4.98e7 | 0.90 |
| 40.0 | 2.26e8 | 2.24e8 | 30 | 1.67e6 | 0.99 |

units n/µC/sr/MeV.

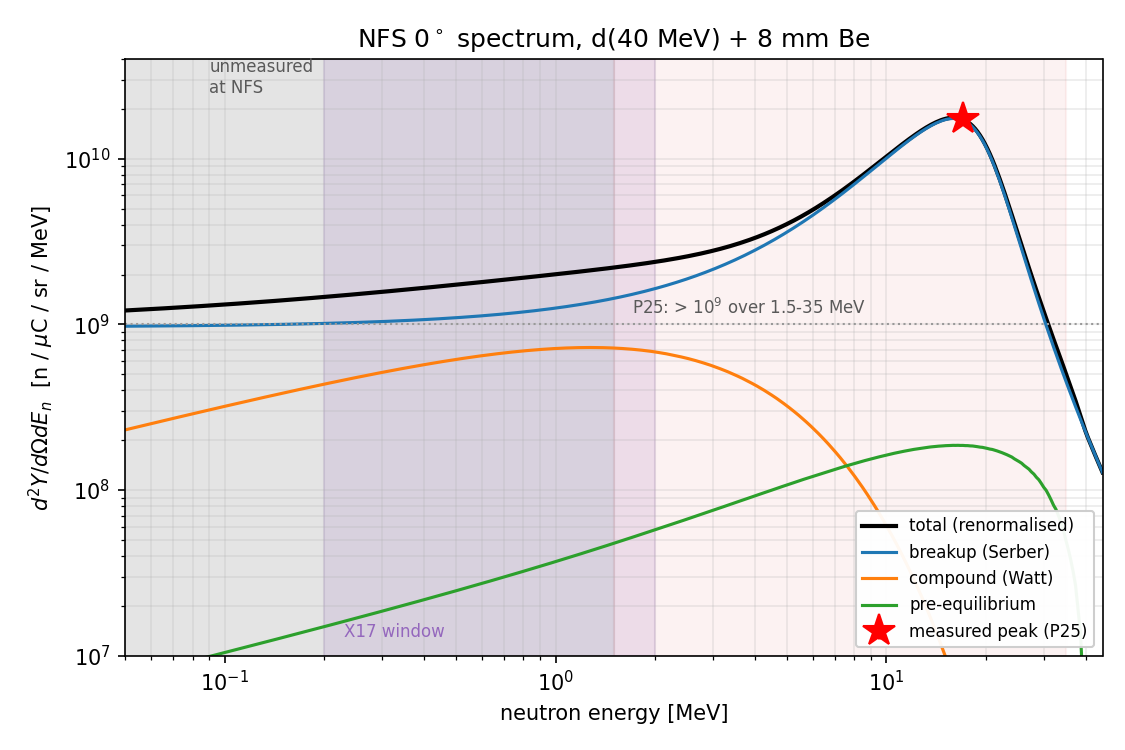
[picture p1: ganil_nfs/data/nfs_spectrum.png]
NFS 0-degree spectrum


### 5.3 How much to trust it

Validated:

| test | model | measurement | verdict |
|---|---|---|---|
| Peak position | 15.9 MeV | 17.0 MeV | 1 MeV low, shape slightly soft |
| Peak height | anchored | 17.3e9 | by construction |
| > 10⁹ over 1.5–35 MeV | fails above ~30 MeV (5.1e8 at 35 MeV) | holds to 35 MeV | **model tail too soft** |
| Flux at 5 m, 50 µA, all E | 5.0×10⁷ n/cm²/s | "close to 10⁸" | factor ~2, consistent with the soft tail |
| Flux at 5 m, 50 µA, near 14 MeV | 3.3×10⁶ n/cm²/MeV/s | 5×10⁶ | 1.5× low, same cause |
| 4π integral | 0.017 n/d | 0.058 n/d | **factor 3.4 — do not use this model for 4π normalisation** |
| Spot geometry | 43.5 mm at 740.6 cm | 44.4 ± 0.4 mm | 2 %, good |

Read that as: **the 0° shape between ~2 and ~25 MeV is good to tens of percent
after renormalisation; the high-energy tail is too soft; the 4π normalisation is
wrong; and below 1.5 MeV nothing is validated at all.** The 4π discrepancy
probably lives in my Kalbach angular implementation being too forward-peaked,
which does not affect the 0° numbers we use — but it is unresolved, so the
model's job is shape at 0°, nothing else.

**The sub-MeV extrapolation is the weak point and it is the region we want.**
Below ~1.5 MeV the model's yield is 60–75 % *breakup*, which is physically
implausible — evaporation should dominate there. What is happening is that the
Serber energy distribution has a (E_n − ε_d/2)⁻³ tail that the model was never
fitted against at E_n ≪ ε_d/2 (Harrig's 16 MeV data are the only low-E_n
constraint in M23's fit). Treat the compound column as a **lower bound** on the
sub-MeV yield and the total as a soft upper bound. That is roughly a factor 3–4
band: 3.2×10⁸ – 1.3×10⁹ n/µC/sr/MeV at 100 keV.

### 5.4 Quasi-monoenergetic p + thin converter

Measured during commissioning with 31.9 MeV protons (L21):

| converter | QME peak | peak fraction of 0° neutrons | 0° yield above 27 MeV | flux at 5 m |
|---|---|---|---|---|
| ⁷Li 1.5 mm | 29.7 MeV | 49 % | (1.77 ± 0.21)×10⁹ n/sr/µC | 1.42×10⁵ n/cm²/s (20 µA) |
| ⁹Be 0.5 mm | 29.5 MeV + bump at 26.9 MeV | 32 % | (1.61 ± 0.19)×10⁹ n/sr/µC | 3.22×10⁵ n/cm²/s (50 µA) |
| ⁹Be 8 mm (thick, protons) | continuum | — | (29.4 ± 4.7)×10⁹ n/sr/µC above 2 MeV | 5.88×10⁶ n/cm²/s (50 µA) |

Reactions: ⁷Li(p,n)⁷Be, Q = −1.644 MeV, the g.s. and 0.423 MeV state unresolved
because proton straggling in the converter exceeds 1.2 MeV; ⁹Be(p,n)⁹B,
Q = −1.850 MeV, with the 2.345 and 2.780 MeV states making the 26.9 MeV bump.
GANIL quotes the QME peak as tunable **between 5 and 30 MeV** with a maximum TOF
hall flux of 2×10⁵ n/s/cm². All of these carry a low-energy continuum tail.

Yield uncertainties: 12 % for thin converters, 16 % for thick, dominated by the
charge measurement (10 % / 15 %).

---

## 6. Time structure, TOF and energy resolution

### 6.1 What has been used

| campaign | rate | flight path | current | source |
|---|---|---|---|---|
| 2019/2021 commissioning (protons) | 22 kHz "(N=400)" — see the §2 warning | 15.74 / 15.74 m | 20–80 nA (activation) | L21 |
| 2025 PS-PPAC monitor (d) | 440 kHz (N = 200), period 2.27 µs | 7.406 m | 7.60 ± 0.05 µA | P25 |
| Medley light-ion run (d) | ≈1 MHz | ≈5 m | — | M25 |

### 6.2 Wrap-around — the constraint that decides our run plan

Neutrons slower than the limit below are overtaken by the next bunch and their
TOF is ambiguous. From `nfs_beam.wraparound_limit_MeV()`:

| rate | period | limit @ 5 m | limit @ 7.4 m | limit @ 10 m | limit @ 20 m |
|---|---|---|---|---|---|
| 8.8 MHz | 114 ns | 7.8 MeV | 15.3 MeV | 27.6 MeV | 71.7 MeV |
| 1 MHz | 1.00 µs | 126 keV | 273 keV | 486 keV | 1.84 MeV |
| 440 kHz | 2.27 µs | 25 keV | 54 keV | 96 keV | 382 keV |
| 88 kHz | 11.4 µs | 1.0 keV | 2.2 keV | 3.9 keV | 16 keV |
| 22 kHz | 45.5 µs | 65 eV | 140 eV | 250 eV | 1.0 keV |

**At 440 kHz and ≤10 m we can see down to ~100 keV with no wrap-around.** At
1 MHz and 20 m the limit is 1.8 MeV, which would destroy the measurement we
want. This is a free parameter we choose, and the correct choice is a *low*
rate at a *short* flight path. That the intensity scales with the rate is the
price; at 440 kHz the facility is already running only 1 bunch in 200.

Contrast with n_TOF EAR2, where the >1 ms thermal gate was an analysis in
itself: at NFS there is no wrap-around problem in our energy window at all.

### 6.3 Time of flight and energy resolution

TOF at the 2025 monitor position, and the resolution from
dE/E = γ(γ+1)√((dt/t)² + (dL/L)²) (Ledoux & Ridikas):

| E_n [MeV] | TOF @ 7.4 m [ns] | dE/E @ 7.4 m (1 ns, 1 cm) |
|---|---|---|
| 0.1 | 1692 | 0.30 % |
| 0.2 | 1197 | 0.32 % |
| 0.5 | 757 | 0.38 % |
| 1.0 | 535 | 0.46 % |
| 2.0 | 379 | 0.59 % |
| 5.0 | 240 | 0.88 % |
| 10 | 171 | 1.22 % |
| 17 | 132 | 1.59 % |
| 40 | 87 | 2.46 % |

Measured performance: **80 ps electronic time resolution**, ~1 ns achieved with
an EJ309 detector, giving **better than 0.4 MeV FWHM at 30 MeV** on a 15.74 m
flight path (L21). Design studies promised ~0.5 % over the whole range at 10 m
with the 100 ps LINAG time spread, and <5 % everywhere with 1 ns detectors (R04).
GANIL quotes <1 % with fast detectors, <5 % at 40 MeV with HPGe (G24).

For us this is comfortable: at E_n ≈ 1 MeV, 0.5 % is 5 keV, far finer than the
E\* structure we are resolving. **Neutron energy is not a limiting resolution
anywhere in this measurement** — the opening-angle resolution is.

---

## 7. The sub-2-MeV problem, and the alternatives

The X17 kinematics want E\* near 20.6 MeV, i.e. **E_n ≲ 2 MeV** (`PLAN` §1.2).
Three facts collide:

1. NFS's d+Be spectrum peaks at 17 MeV and is measured only down to 1.5 MeV.
2. Below 1.5 MeV, the spectrum is **unmeasured**, and the only available model
   is unvalidated exactly there (§5.3).
3. The best-guess model yield at 0.2–2 MeV is ~1.5–2.4×10⁹ n/µC/sr/MeV, i.e.
   **8–14 % of the peak value, per MeV** — not the ~1/17 the PLAN §5.1 assumed
   from reading the log plot, but the same order.

So the thin bottom edge is thinner than the peak but not catastrophically so,
*if the model's sub-MeV extrapolation holds*. That "if" is the whole question,
and it cannot be closed from the literature. It needs either the NFS team's own
MCNPX/simulated spectrum below 1.5 MeV, or a measurement.

Options if the d+Be tail is not good enough — in the order I would rank them:

**(a) Lower the deuteron energy.** SPIRAL-2 delivers deuterons from 0.75 MeV/u.
A thick-Be spectrum from, say, 10–15 MeV deuterons is far softer (the breakup
bump sits at ~½ε_d) while still using the high-power rotating converter. This is
the cheapest lever and nobody in the NFS literature discusses it because their
users all want the 14 MeV bump. `nfs_beam.thick_target_yield(e_d0=...)` covers
it directly — worth scanning ε_d as a first calculation.

**(b) D(d,n)³He with a low-energy deuteron beam.** Explicitly named as an NFS
capability (R04 §2.1): "in the low energy range (E_n < 8 MeV) mono-energetic
neutrons can be produced by the ²H(d,n)³He reaction", solid (D-in-Ti, ~1 mg/cm²)
or gas target. At low ε_d this is the classic ~2.45 MeV monoenergetic DD source,
tunable upward with beam energy. **This lands exactly where our physics wants
to be, and it is monoenergetic** — no folding against a continuum, and E\* is
fixed rather than smeared. The catch is flux: a 1 mg/cm² target is thin, the
yield scales with the beam power the target survives, and R04 says "further
studies along these lines are urgently needed", i.e. it may never have been
built. **This is the first thing to ask GANIL about.**

**(c) ⁷Li(p,n)⁷Be near threshold.** Q = −1.644 MeV, threshold 1.881 MeV. With
protons a little above threshold the 0° neutron energy runs from ~30 keV upward
and is kinematically collimated. SPIRAL-2 goes down to 0.75 MeV protons, so the
whole near-threshold region is accessible. GANIL only advertises the QME peak
between 5 and 30 MeV, but nothing forbids the low-energy end. Flux is the issue —
the thin-Li converter caps at 20 µA.

**(d) Moderation.** R04 §2.2 studied a Be + D₂O sandwich moderator giving
~4×10¹¹ n/cm²/s over 3–100 keV at full 5 mA beam power. Far too soft for us
(we want ~1 MeV, not keV) and it destroys the TOF resolution via slowing-down
time, but it demonstrates that the facility has thought about tailoring the
spectrum downward.

**(e) Accept a higher E_n.** The shoulder slides from 109.6° at rest to 99.3° at
2 MeV and 65.7° at 14 MeV (`PLAN` §1.2), into the IPC-rich small-angle region.
This is Q2 in the PLAN's open questions and it is a physics decision, not a
facility one.

---

## 8. Backgrounds

| item | value | source |
|---|---|---|
| Thermal neutron contamination | **≤ (3.85 ± 0.43)×10⁻⁵** of fast, upper limit, in the TOF hall | P25 |
| Collimator design intent | concrete / borated PE / iron / lead layers, conical bore, explicitly to minimise n and γ background in the TOF hall | L21 |
| γ flash | "known to be very penalizing… will probably be strongly reduced at NFS"; M25 calls the γ-flash characteristics "suitable"; used routinely as the TOF t₀ reference | R04, M25 |
| γ peak width | σ ≈ 1 ns, i.e. detector-limited, at 15.74 m | L21 |
| n/γ discrimination | needed — L21 note a residual prompt-γ peak survives PSD in "neutron-identified" events | L21 |
| Beam line | evacuated through the TOF hall to suppress air scattering; a magnet deflects the primary beam to a Faraday cup | L21 |
| TOF-uncorrelated fission background | 1.40×10⁻⁴ of correlated (the measurement behind the thermal limit) | P25 |

The thermal suppression is a genuinely large win for us: at n_TOF the
²⁷Al(n,γ) 7.72 MeV capture line dominated the trigger background, and a
3.9×10⁻⁵ thermal fraction essentially removes it.

Backgrounds *not* characterised anywhere in the literature, which we would have
to simulate or measure ourselves: fast-neutron elastic recoils in the drift gas
and vessel, ³He(n,p)t protons in the cell, (n,xn) and (n,charged) in the vessel
walls, and beam-correlated room background over 28 m of hall.

---

## 9. Rates for our geometry

On-axis differential fluence rate is simply Y(E_n) × I / L², independent of the
collimator aperture (the aperture sets the illuminated *area*, not the on-axis
intensity). From `nfs_beam.fluence_rate()`, using the data-normalised model:

| configuration | total 0.05–45 MeV | 0.2–2 MeV | 1–3 MeV |
|---|---|---|---|
| 5 m, 50 µA | 5.0×10⁷ | 7.3×10⁵ | 9.6×10⁵ |
| 7.41 m, 7.6 µA (2025 conditions) | 3.5×10⁶ | 5.0×10⁴ | 6.6×10⁴ |
| 10 m, 50 µA | 1.3×10⁷ | 1.8×10⁵ | 2.4×10⁵ |
| **13.6 m (8 cm spot), 50 µA** | 6.8×10⁶ | **9.8×10⁴** | 1.3×10⁵ |
| 20 m, 50 µA | 3.1×10⁶ | 4.5×10⁴ | 6.0×10⁴ |

units n/cm²/s. Two things to note against `PLAN` §5.3, which assumed
1.5×10⁶ n/cm²/s over an 8 cm spot:

- That figure was the **whole-spectrum** flux. In the 0.2–2 MeV window we
  actually want, the flux at 13.6 m (the 8 cm-spot distance) and 50 µA is
  **9.8×10⁴ n/cm²/s**, about 15× lower. The X17/day numbers in PLAN §5.3
  should be re-derived from a proper fold, not scaled from the total.
- Every rate scales linearly with the repetition rate we choose. 50 µA is the
  authorised maximum, which corresponds to some particular N; running at a low
  rate to avoid wrap-around (§6.2) may cap the current well below 50 µA. **Ask
  GANIL what current is available at 440 kHz** — this is Q3 in §10 and it moves
  the rate estimate by up to an order of magnitude.

---

## 10. What the literature does not pin down

Questions for the NFS team (X. Ledoux, xavier.ledoux@ganil.fr):

1. **What collimator apertures exist?** Only 25.55 mm is documented. An 8 cm
   spot at 5 m instead of 13.6 m would recover a factor 7.4 in flux.
2. **What is the d+Be spectrum below 1.5 MeV?** They will have an MCNPX or
   Geant4 model of the converter. This single answer decides the study.
3. **What deuteron current is available as a function of repetition rate?** The
   50 µA maximum is quoted without a rate.
4. **Has the D(d,n)³He monoenergetic option ever been implemented?** (R04 §2.1.)
   And can the LINAC actually deliver a few-MeV deuteron beam to NFS?
5. **What is the achievable spot at a given flight path, and can the second
   mid-hall collimator be removed or bypassed?**
6. **Is the γ flash quantified?** Everything published is qualitative.
7. Sanity check on our own arithmetic: is the model's 0.017 n/d 4π yield or
   GANIL's 0.058 n/d the right number for 40 MeV d + 8 mm Be?

Also worth chasing but not blocking: the digitised P25 Fig. 11 (ask the authors
for the table — it is the only real NFS spectrum), Saltmarsh's tabulated
d(40)+Be spectra (NIM 145, 81 (1977), possibly in EXFOR — the IAEA EXFOR
endpoints were unreachable while compiling this), and Meulders 1975 for the
angular dependence.

---

## 11. Files in this directory

| file | what |
|---|---|
| `README.md` | this document |
| `nfs_beam.py` | the beam model: thick-target d+Be yield, geometry, TOF/wrap-around/resolution helpers. Run it for a self-check; `--write` regenerates the CSV |
| `data/nfs_measured_anchors.csv` | every published *measured* number, machine-readable, for validating a simulation |
| `data/nfs_dbe40_0deg_model.csv` | 0° spectrum, 0.05–45 MeV, total + 3 components, data-normalised |
| `data/nfs_spectrum.png` | the same, plotted, with the measured anchor and the unmeasured region marked |
| `refs/` | text extractions of the primary sources |

Maps onto `facility/` in the `PLAN_GANIL_NFS.md` §"Proposed repo structure";
kept as `ganil_nfs/` because it is facility documentation rather than analysis.

### Sources

| key | reference |
|---|---|
| **P25** | J. A. Pavón-Rodríguez *et al.*, "A new beam monitor at NFS/SPIRAL2 based on position-sensitive PPACs detecting fission fragments from ²³⁸U(n,f)", EPJ A **61**, 277 (2025); [arXiv:2601.07896](https://arxiv.org/abs/2601.07896). **The only absolute differential measurement of the NFS neutron beam.** |
| **L21** | X. Ledoux *et al.*, "First beams at Neutrons For Science", Eur. Phys. J. A **57**, 257 (2021); [arXiv:2110.02282](https://arxiv.org/abs/2110.02282). Commissioning: facility description, p+Li/p+Be QME spectra, yields. |
| **M25** | L. de Arruda *et al.*, "Reconstruction of the GANIL-NFS spectral neutron flux with Medley using elastically scattered protons", EPJ Web Conf. **322**, 08006 (2025). Independent flux cross-check, 2–25 MeV. |
| **M23** | J. T. Morrell, L. A. Bernstein *et al.*, "Secondary neutron production from thick target deuteron breakup", Phys. Rev. C **108**, 024616 (2023); [arXiv:2212.00218](https://arxiv.org/abs/2212.00218). The parameterisation implemented in `nfs_beam.py`. |
| **R04** | X. Ledoux, D. Ridikas, "Neutrons For Science (NFS) at SPIRAL-2 (Part II: pulsed neutron beam)", CEA/DAPNIA, [OSTI 20736734](https://www.osti.gov/etdeweb/servlets/purl/20736734). Design study: resolution, rep-rate choice, moderators, monoenergetic options. |
| **G24** | GANIL, [NFS facility page](https://www.ganil-spiral2.eu/scientists/ganil-spiral-2-facilities/experimental-areas/nfs/). |
| **I24** | IN2P3, [NFS fact sheet](https://www.in2p3.cnrs.fr/sites/institut_in2p3/files/news/2024-08/NFS_EN.pdf), April 2024. |
| **S20** | M. Di Giacomo *et al.*, "Proton beam commissioning of the SPIRAL2 Single Bunch Selector", JINST **15**, T12011 (2020). |
| **NFS-2017** | X. Ledoux *et al.*, "The Neutrons for Science facility at SPIRAL-2", EPJ Web Conf. **146**, 03003 (2017). *Could not be retrieved — both mirrors refused. Worth fetching; it is the facility's own spectrum paper.* |
| **Salt77** | M. J. Saltmarsh *et al.*, NIM **145**, 81 (1977). d(40 MeV)+thick Be at 0°–90°; P25 shows the NFS beam agrees with it. *Not retrieved — paywalled, EXFOR unreachable.* |

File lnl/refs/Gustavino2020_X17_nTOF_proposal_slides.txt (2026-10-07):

===== page 1 =====
Search of the X17 Boson @ n_ToFCarlo Gustavino, INFN Roma
Outline:
Introduction
X17 search @ ATOMKI
X17 search @ n_ToF
Possible Setup
Conclusion

===== page 2 =====
Introduction
Krasznahorkay, A.J.; et al.:
"Observationof AnomalousInternalPairCreationin8Be: A PossibleIndicationof a Light, NeutralBoson".
Physical Review Letters.116(42501): 042501 (2016).
Krasznahorkay, A.J.; et al.:
"New evidencesupportingthe existenceof the hypotheticX17 particle".
arXiv:1910.10459v1[nucl-ex] (23 October2019). 
Reaction MX17(MeV) DMX17_STAT DMX17_SYST Statistical evidence
7Li(p,e+e-)8Be 16,70 0,35 0,50 >5 sigma
3H(p,e+e-)4He 16,84 0,16 0,20 >7,2 sigma
Asignificantanomalyhasbeenrecentlyobservedintheemissionofelectron-positronpairsin
the7Li(p,e+e-)8Beand3H(p,e+e-)4Hereactions.
vThisanomalyhasbeeninterpretedasthesignatureofaJp=1+particle(hereafterX17)not
foreseeninthestandardmodelofparticlephysics.
vX17bosoncouldbeamediatorofafifthforce,characterizedbyastrongcoupling
suppressionofprotonscomparedtoneutrons.
vThisevidence/scenarioispresentlynotconfirmedorexcludedbyotherexperimentsor
groups.

===== page 3 =====
3H(p,e+e-)4He reaction@ ATOMKI
Ep=0.9 MeV
Q=19.8 MeV
Ep=0.9 MeV
E0+=0.53 MeV
E0-=1.8 MeV
0 0+
21.1
20.2
0-
0+
3H + p
Ep=1.7 MeV G(0+)=0.5 MeV
G(0-)=0.84 MeV

===== page 4 =====
3H(p,e+e-)4He setup @ ATOMKI
v3H adsorbed on  Tilayer
v6 plastic scintillator 82x86x80 mm3
v6 double-sidedsiliconstrip detector  (3 mm 
wide strips, 0.5 mm thick)
v1 mm thickcarbon fibertube
vEp=0.9 MeV
Similarsetup for the p(7Li,e+e-)8Be reaction
Target
Carbon fiber tubePlastic scintillator
Silicon strips e-
e+

===== page 5 =====
3H(p,e+e-)4He 3He(n,e+e-)4He
Basic idea: Exploitingthe  conjugatereaction:
0 0+
3He + n
21.1
20.2
0-
0+
3H + p
X17 @ nToF
Q=20.57 MeV
En=0-2 MeV
E0+=negative
E0-=0.7 MeV
En=0.7 MeV
G(0+)=0.84 MeV
G(0-)=0.5 MeV

===== page 6 =====
Possibile setup
TPC with MPGD 
(GEM/µMegas/RWELL) 
He3target
n-beam
e-
e+
E.M. calorimeter
(e.g. Scintillatortileswith SiPM)
TPC: tracks and vertex recognition
e.m. calorimeter: T0for the TPC, energy measurement
TPC+calorimeter: background rejection

===== page 7 =====
Target
DEFAULT target: commercial3He tubes
Diameter: 1 inch(25.4 mm)
Pressure: 30 bar
Thickness: 500 µm
Material: 344 stainlesssteel
Lenght: 10-100 cm
X0= 0.029
Costfor a 20 cm long tube: 10 kEuro

===== page 8 =====
Tracker
TPC with MPGD readout (GEM/µM/RWELL)
MPGD anularend plate
Central annular 
cathode
5 cm
10 cm
Gas drift volumes
Ar/CO2/CF4
Ar/CO2
He3target
15 cm
15-20 cm 15-20 cm
ED
ED
ED= 0.2÷0.5 kV/cm
Thikcness (um) X0 (cm) % X0
Cu 3 1,43 0,021
kapton 50 28,6 0,017
glue 30 33,5 0,009
MILLIFOAM/honeycomb 3000 1312,5 0,023
glue 50 33,5 0,015
kapton 30 28,6 0,010
0,096
Cylindrical Supports
Layering of inner/outer cylinder including field cage (in Cu)
Field cage (inner/outer) cylinders ~0.1 radiation lenghts

===== page 9 =====
Eachquadrantcouldbe dividedin n.128 r-strips(0,78 mm pitch–maxlength~ 15 cm) 
and n.640 (128-192-320) φ-stripswith a pitchof 12 –8 –5 mrad(roughly0,58 –0,62 –
0,53  mm). Globallyeachquadrantwillbe readoutwith 768 (analog) electronic
channels768x4=3072 channel.
10 cm
He3target
15 cm
15-20 cm 15-20 cm
ED
ED
MPGD anularend plate
Tracker
TPC MPGD readout (GEM/µM/RWELL)

===== page 10 =====
The most common MPGD as readout options:
•triple-GEM •µ-RWELL 
•MicroMegas
ALICE TPC KEK TPC
 never used as TPC readout.
foreseen as Cylindrical-
RWELL for CREMLIN-plus
MPGD END PLATES
Micromegas looks the best solution (known technology and limited ion feedback)

===== page 11 =====
E.M. Calorimeter
In progress:
Scionixej200 tiles with SiPMreadout
TPC+µMegas
end plate 
e.mcalorimeter+ SiPMreadout
s ~ 1,64 mm
Target

===== page 12 =====
Signal/background
Target lenght(cm) 20
diameter(cm) 2,54
Pressure (bar) 30
rate p(s-1) 1,3E+06
rate gamma (s-1) 13
rate IPC (day-1) 66,3
vThe e+epairsdue to X17 havea uniquesignature., i.e. theyproduce  
e+e-pairswith Etot~9+9 MeVatlarge angle (~120°).
vThe irreduciblebackground isdue to IPC. Asthe hungariangroupdid, 
the signalisthe net area of the IPC peakatlarge angle.
vThe 18 MeVshowerof the 3He(n,g)4He reaction can be easily
identified(single showerof ~18 MeV, no TPC tracks)
vCosmicraybackground (muon) can be measuredwith off spill
measurements.
vGamma flash are in advance(T>1300 ns ifEn<1 MeV) and well
identifiedby the calorimeterand the TPC.
vProtonsdue to (n,p) reactionhaveatverylowenergy(Q=764 keV) 
and cannotcross the 500 µm steeltube for Ep<15 MeV.
vRate of X17 eventsisprobablylowàlong measuringtime and R&D to 
increasethe numberof events. 
Preliminar!

===== page 13 =====
Conclusion(1)
A spectacular anomaly has been recently observed in the emission of electron-positron pairs 
in the 7Li(p,e+e-)8Be and 3H(p,e+e-)4He reaction.
This anomaly has been interpreted as the signature of a particle (X17 boson) not foreseen in 
the standard model of particle physics. 
The X17 boson could be a mediator of a fifth force, characterized by a strong coupling 
suppression of protons compared to neutrons. 
This scenario may be related to Dark Matter and to the 3.6 ssanomaly of muon magnetic 
moment. 
A new measurement to confirm (or reject) the claimed is mandatory. New informationson X17 
coupling are necessary to define a theoretical framework. 
The proposed experiment at n_ToFis a study of X17 by an indipendentcollaboration, using an 
improved setup and exploiting a new nuclear process. 
The goal is to measure the parameter of X17 boson (mass, parity, life time..) and to shed light 
on the protophobicnature of fifth force (neutron induced reaction).
Standard 3He(n,e+e-)4He and 3He(n,g)4He reactions are also of great interest in nuclear physics, 
providing an important experimental footing for "ab initio" calculations.

===== page 14 =====
Conclusion(2)
The proposed setup (large acceptance TPC and calorimeter) allows the identification of e+e-
pairs at large relative angle and a background rejection better than the ATOMKI group. 
Long data taking and specific R&D (e.g. target density) is needed to increase statistics.
N.B. The calorimeter and the TPC are very well suited  also for other experiment at n_ToF. 
Concerning X17, a positive result of the 3He(n,e+e-)4He study could stimulate a successive 
study of the 7Be(n,e+e-)8Be, with the same setup.
TENTATIVE ROADMAP
•February 2021: TDR of TPC and Calorimeter  
•May 2021: LoIto INTC requiring a beam test
•October 2021: protoypesand beam test
•December 2021: Submission of a proposal to INTC
•May-june2022: 3He(n,e+e-)4He measurements at n_ToF
Grazie per l'attenzione!

===== page 15 =====
SPARES

===== page 16 =====
REAZIONE7Li(p,e+e-)8Be
NIM, A808, 21 (2016)
18.2
17.6
3.0
0
1+
1+
2+
0+
Ep=1030 keV
Ep=441 keV
7Be + p

===== page 17 =====
•768 chs/quadrant (n.128 r-strips + n.640 φ-strips)  àn.6 APV25
•3072 chs/end-plateàn.24 APV25
•6144 chs/TPC   àn.48 APV25 (n.3 x (8 master + 8 slave))  ………..    7152 CHF
•n.3 ADC ……………………………………………………………………………………..    3708 CHF
•n.3 FEC  ……………………………………………………………………………………..    4785 CHF
•n.1 SRS-crate…………………………………………………………………………….      809 CHF
•Connectors, cablesetc……………………………………………………………...   3000 CHF
TOT     19.454 CHF
FEE & DAQ (tentativeestimate)
L'elettronicaha unaprofonditàdi 5x192= 5 µsàdrift max=20 cm
CostoTotaleelettronica40.000 CHF

===== page 18 =====
TPC (tentativeestimate)DearCarlo
I'vemade an estimate (+/-30%) for the production of:
-Item 1 -->1 x AnodeMicromegasdetector :
-30 cm activearea with
-Resistive protection
-Radialand angle strips
-3072 Channels
-24 panasonicconnectorsor equivalent
-Item 2-->1 x TPC fieldcage:
-20cm high
-oneInner tube 10cm diameter
-oneOuter tube 30cm diameter
-Gluedframesatbothendsfor gas tight assemblywith o-rings
-2 resistorschainper tube
-No shielding
-Single layerstripson 0.2mm Flexglass/epoxytube
-item3-->1 x Cathodecircuit:
-30cm activearea
Item1:
Design costbetween3000 to 6000 CHF (dependingon symmetrieswecan findto simplifythe layout)
Toolingcosts: 2500 CHF
Detector production : 6000 CHF
Item2:
Design cost: 1000 CHF
Toolingcosts: 1500 CHF
Field cageproduction : 4500 CHF
Item 3:
Design cost: 300CHF
Toolingcosts: 300 CHF
Cathodeproduction : 800 CHF
These3 partscan be assembledwith ssimplescrewdriver.
STIMA COSTI (+/-30%, chiaviin mano)
Costototale(mezza camera) 21.000 CHF
CostoTotale(camera intera) 36.000 CHF

===== page 19 =====
CALORIMETRO ELETTROMAGNETICO
-BacchetteEJ200 6x6x500 mm: 65 Euro l'una
(minimo26 bacchette) SCIONIX.PREVENTIVI 
ONLINE
SiPMADVANSID (Bias~30 Volts, 3x3mm) 21 Euro 
l'una(se ne compro100). Esistonoanche4x4
A paritàdi prestazioni, ilcostodelloscintillatore
scalacome ilquadratodel raggiointernodel 
calorimetroàèmolto importanteilraggio
esternodellaTPC. PRIVILEGIARE UN RIVELATORE 
COMPATTO! Aumentailbackground off beam?

===== page 20 =====
Micromegas better than GeM(no ion feedback) or R-wells (too "young" technology)
KEK TPC
MPGD END PLATES

===== page 21 =====

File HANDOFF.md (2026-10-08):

# Handoff

## LNL ⁸Be Geant4 feasibility — updated 2026-10-08 (dylan-MS-7C84)

**Resume:** read `lnl/FEASIBILITY_SIM.md` §0. The LNL Geant4 feasibility is done. What is open are
the questions for the collaboration (SiPM-wall timing, LS readout), the emails, and the IPC shape.

**Goal:** Dylan (going to bed): follow through the LNL feasibility on lxplus overnight (condor only, outputs
on EOS), chase threads of interest, republish when the numbers change.

**Done:**
- **Runs** (all finished, `/eos/experiment/ntof/data/x17/lnl/`, 2.0 TB raw ROOT):
  - L1/L2 as built, then the same with big plastics (`_bigP`: `--big-plastic 75 75 5 --no-ls
    --sipm-readout 20 0`) and with 20 SiPM bars (`_sipm20`);
  - L3 γ lines: 8Be (+`_x20` 2×10⁸ γ; `_bigP_x10`), 19F, 7Li, `gam_Al28` (new line set);
  - L4 cosmics, one live day, as built and big plastics;
  - L5 chamber/backing scan; L6 E0 6.05.
- **MX17_Full_Geant `lnl`:** merged `trigger_plastics` (a424eed), frozen binary
  `bin/mx17_full_sim_lnl_a424eed`, `gam_Al28` added to `submit_lnl.py`. Pushed.
- **Pipeline** `lnl/sim/lxplus/`:
  - `lnl_reduce.py` = `ill_pairs` reduce + `seg_reduce`;
  - `lnl_time.py` = per-arm scintillator times;
  - `lnl_merge.py` → `$E/sel/<run>_<sample>_sel.npz`;
  - `lnl_pipe.sh reduce|time|remerge|merge|status`, idempotent.
  - lxplus copy: `/afs/cern.ch/work/d/dneff/git/x17_lnl/analysis/`.
- **Analysis** `lnl/sim/lnl_geant.py` (`--figs` rebuilds the figures only) → `lnl/out/geant/`.
  `lnl/sim/fetch_sel.sh` copies the tables to `lnl/sim/sel/` (gitignored, ~100 MB).
- **Result:** 3σ at R(ATOMKI), Li₂O 300 at 1.10 MeV, 1 µA:
  - as built: 15–24 d (counting – template fit);
  - big plastics: 1.2–1.6 d.
- **Findings:**
  - pair-tag is 3.3 % as built (EPS_REST was really 0.084), 23 % with big plastics;
  - E_sum removes γ₁ (with LS, or with big plastics);
  - **cosmics need an upper E_sum edge plus 3° segments or a ≤ 0.4 ns TOF**, because 15° segments fail;
  - EPC, accidentals and DAQ are negligible;
  - CFRP chamber (an Al wall doubles σ_θ);
  - the E0 6.05 line is invisible to the trigger.
- **Written up:**
  - `lnl/FEASIBILITY_SIM.md` (new);
  - `lnl/README.md` read-first block;
  - pointers in `ESTIMATES.md`, `GEANT_PREP.md` §0 and `lnl_rates.py`.
- **Published:**
  - the deck was rebuilt with 8 new or replaced slides and is live at notes/lnl-x17-feasibility.html;
  - `/facilities/lnl.html` was updated and deployed (dylan-cern-site 1977ee7).
- **Basics appendix** (2026-10-08, Dylan is new to the channel): deck slides 15–33, built by
  `lnl/deck/appendix.py` from `lnl/appendix_calc.py` → `lnl/out/appendix/*.csv`. It covers the Van de Graaff,
  energy/time structure, p vs n, the rate chain, thin vs stopping targets (main slide 6), why γ₀ is the
  unit, the chamber + Highland model fitted to L5 (**analytic stand-in** for walls not simulated), level
  schemes, E* bookkeeping (C1a–c: Q + ⅞E_p, any E_p vs resonances, X17 leverage E*−m), M1/E1/E0, the
  bump, boost (β 0.006 → 0.3°), edge vs E_p, off-resonance (a test, not more yield), glossary. Republished.

**Next steps:**
1. Ask the collaboration:
   - the SiPM-wall time resolution (TOF needs ≲ 0.4 ns);
   - whether the LS can be read at LNL. Without them: 19 d, and no cosmic E_sum edge.
2. Emails (Dylan's): LNL (Selva/pacbeams), T. Marchi.
3. The IPC shape: the fit with M1/E1 free is ×2.3–3 slower. Add Zhang–Miller M1–E1 interference, or plan
   0.8 MeV E1-shape runs.
4. Optional: rerun cosmics for `_sipm20` (it uses the as-built cosmics now); ¹¹B and beam-halo sims.
5. Optional: a Geant4 L5-type run of the improved chamber options (CFRP 0.2 mm, wider tube, Be) to
   replace the appendix's Highland stand-in, and see whether ~4° shortens the days.
6. **EOS:** the 2 TB of raw ROOT in `…/x17/lnl/L*/` can go once the tables are final. Only the `sel/` and
   `parts_*` are needed. Ask Dylan before deleting.

**Gotchas:**
- `condor_submit` from an EOS cwd hangs or fails. `lnl_pipe.sh` now `cd`s to the AFS job dir.
- The background templates are KDE-smoothed (5°). Without it, empty IPC bins faked a ×50 Fisher gain.
- The pointing cut D is calibrated to 90 % of X17 segments (135 mm at 15°, 57 mm at 3°), not from the
  nominal resolution.
- `pkill -f <pattern>` matches your own shell command. Use `pgrep` with a bracket trick, or a PID.
- dylan-cern-site still has the earlier session's uncommitted `x17/analysis.html`, `pages/x17/analysis.html`
  and `sw.js` (not mine; left alone). `ill/sim/lxplus/gdiag.py` and two `walls_CFRP_*.csv` here belong to
  the ILL session (uncommitted, left alone).

**Key files:** `lnl/FEASIBILITY_SIM.md`, `lnl/sim/lnl_geant.py`, `lnl/sim/lxplus/lnl_pipe.sh`,
`lnl/out/geant/reach_geant.csv`, `lnl/deck/build_deck.py` (+ `appendix.py`; run `lnl/appendix_calc.py` first
from `lnl/` with the nTof_x17 venv python, then `deck/build_deck.py`, then `add-note.py … --force --deploy`).

## ILL rate walls, He flight tube, entrance window — updated 2026-10-07 (dylan-MS-7C84)

**Resume:** condor sims (G1_tube{Be,Be25,My}) were running; finish the reduce → merge → fits chain, then write §13 + 2 slides.

**Goal:** Dylan's question after the §12 verdict: is the reach pure statistics, can more beam / pressure /
target size buy it back, or do pile-up and accidentals cap it irreducibly? And before calling it impossible,
chase the engineering levers: a He flight tube (../he4_bag) and a better or thinner entrance window than 0.5 mm Be.

**Done (answers so far, from a surrogate, not yet the real fit):**
- **Pressure buys nothing.** G1 is already opaque at 1 bar (99.5 % absorbed), and the yields per absorbed n
  don't depend on pressure. Pressure only shortens the source (≤ 13 % via the vertex).
- **There is plenty of beam.** R_MAX 1.9e10 is just the Ø2 cm spot (`out/beam_spot.csv`): Ø4 cm gives 7.5e10,
  Ø5 cm 1.2e11. S1s says a 25 mm spot radius costs < 5 % acceptance and +0.3°.
- **Three rate walls.** `ill/sim/rate_surrogate.py` is a counting stand-in for the Fisher fit, calibrated on
  the §11 oracle rows; it reproduces as-is to 1.5 %.
  1. **Accidentals ∝ R²·2τ.** As is, with infinite beam, a perfect MM and no dead time, the reach never goes
     below 1.1e-2 (no panel, Esum > 13) or 7.7e-3 (panel, > 14). The ceiling ∝ √(2τ·singles²).
  2. **MM occupancy, exp(−2·occ).** occ 0.22/arm at 1.9e10 caps the useful rate at ~3.3e10 (+7 %). From the
     X17 shifts in the budget rows, the occupancy split is: Al frames ~35 %, Cu ~24 %, air ~15 %,
     PCB/Kapton ~10 %, Be ~7 %. So it comes from stray neutrons captured in the detector.
  3. **DREAM, 298 µs/trigger** (trigger ≈ 7.9e-9/n·R + 2.8e-19·R²). With 1 and 2 fixed: optimum 1.1e11,
     live 0.44, floor 3.7e-3.
  - Only with all three gone is it pure 1/√R: ⁸Be's 1.6e-3 needs ~3e11 n/s (15× today).
- **Window options** (`ill/window_options.py`, analytic). The 0.5 mm Be was sized for 2 bar (G3–G6); G1 at
  1 bar with He behind it has no Δp. **25 µm mylar has no line above 4.95 MeV (C; H gives 2.2).** Any pair
  with a window capture then needs an ≥ 8 MeV partner, and once the air is gone only ³He(n,γ) remains.
  It scatters ~1 % of the beam (bound H, my estimate) against 0.3 % for Be. Kapton contains N (10.83): avoid.
  Be 0.25 mm halves the singles. Al is worse.
- **Geant: `--flight-tube He[:r]`, `--tube-wall Mat:mm` (default Al:1), `--tube-window Mat:mm` (default
  Mylar:0.025)** on MX17 `ill_ring` (commit 2c10ca1, pushed). A He tube runs from the gun plane + 1 mm to the
  cell's upstream face. Overlap-checked. Binary: lxplus `MX17_Full_Geant/bin/mx17_full_sim_tube`; the source
  was copied into the lxplus clone (it was identical to `ill_ring` HEAD beforehand).
- `conservative.py`:
  - `--rate-walls` (+ `--rmax`, default 2e12) writes every rate-grid point for 4 scenarios (as is,
    no Be+air, no ACC, IPC only) × 4 knob settings (MM occ + DREAM / MM ÷10 + 10 µs DAQ / no MM loss /
    no MM loss + no dead time).
  - `best_reach` gained `rates`, `daq_tau`, `occ_scale`, `curve`.
  - `acc_sources.volume` gained a "flight tube wall + window" class.

**In progress / where it stopped:**
- Condor sims submitted 2026-10-07 ~21:10, 10×1e7 each:
  - runs: `$E/C1/G1_tube{Be,Be25,My}` and `$E/C1w/G1_tube{Be,Be25,My}`, all G1 + CFRP ring/cap + He tube;
  - windows: Be 0.5 / Be 0.25 / Mylar 0.025;
  - C1w uses `--bias-wall 300 --bias-thick 20 --bias-air 100`;
  - none were finished at wrap-up.
- `walls` fits on the existing CFRP data (`$E/analysis/cons/walls_CFRP_e13.csv`, `walls_CFRP_e14.csv`) were
  running; the CSVs are written incrementally, so they are complete only once the log ends with `wrote`
  (`/afs/cern.ch/user/d/dneff/condor/ill/cons/walls/logs/*.out`).
- The local driver `ill/sim/lxplus/tube_chain.sh` (sims → submit_reduce_ill + seg_submit → merge_submit →
  cons_submit "tube" with bo_/e14_/walls_ jobs per variant) **died with the session**. Re-run it, or do its
  steps by hand. Careful: rerunning resubmits the reduce if the sims are done; seg_submit skips existing
  outputs, but submit_reduce_ill may not, so check `parts/` first and start from the right step.

**Next steps:**
1. Check the sims: `grep -l 'Run Summary' $E/C1*/G1_tube*/*_job*.log | wc -l` (60 = done). Then the reduce,
   merge and fits as in `tube_chain.sh`.
2. Compare the real fit with the surrogate on `walls_CFRP_*`.
3. For each variant, from the `bo_`/`e14_` budget and `walls_*`:
   - ACC (Be window, air, tube wall);
   - MM occupancy, from the X17 at fixed R;
   - trigger rate;
   - the best reach as is and per knob.

   Key question: does the tube + mylar make accidentals negligible, so the walls become MM occupancy and the
   DAQ? Check that the mylar's extra scattering doesn't add detector singles. G4_MYLAR uses free-gas H
   (S(α,β) only for Be/Al/C/Fe here), so Geant probably underestimates the H scattering by ~2×.
4. Write `FEASIBILITY_SIM.md` §13 "Rate walls and the window". Add slides "Rate walls" (reach vs R curves)
   and "Window & flight tube" after "blocking" in `ill/deck/build_deck.py`. Update "verdict"/"next" if it
   changes. Rebuild with the nTof_x17 venv python and republish (see the section below).
5. **Open design question (Dylan):** every number assumes a two-arm trigger: a per-arm SiPM×plastic
   coincidence in two *different* arms, and a 60–180° fit window. That hides the small-angle part of the
   opening-angle spectrum (both legs in one arm). Dylan would like the unbiased 0–180° spectrum. Study what
   a single-arm (or same-arm two-track) trigger costs: per-arm singles rate → DREAM dead time, and
   accidentals. The per-arm rates are already in `trigger_rates()`. This ties straight into wall 3.

**Gotchas / decisions:**
- The window class in `acc_sources` is still labelled "Be entrance window" even when the window is mylar.
  The label is kept so the scenario names, old CSVs and the deck still match.
- The occupancy model (any foreign MM hit in the 1 µs window kills the event) is pessimistic. A segment fit
  could likely tolerate an unrelated track, so wall 2 is partly a modelling choice.
- The tube wall is 1 mm Al (scattered neutrons → 7.7 MeV). If it shows up in the accidentals, try
  `--tube-wall CFRP:1` or a ⁶LiF lining.

**Key files & commands:**
- `ill/sim/rate_surrogate.py` — surrogate rate scan (reads `sim/analysis_v3/cons/{bo_ringCFRP,e14}.csv`).
- `ill/window_options.py` — window materials: captures/n by line, scattering.
- `ill/sim/lxplus/conservative.py --rate-walls` — the real rate scan (on lxplus via `cons_submit.sh`).
- `ill/sim/lxplus/tube_chain.sh` — the pipeline driver for the three tube variants.
- Copy results locally: `scp lxplus:$E/analysis/cons/{walls_*,bo_tube*,e14_tube*}.csv ill/sim/analysis_v3/cons/`.

## ILL conservative reach — wrapped up 2026-10-07 (dylan-MS-7C84)

**Status: done.** Write-up `ill/FEASIBILITY_SIM.md` §10–12; deck `ill/deck/build_deck.py` → live at
https://dylan-neff.web.cern.ch/notes/ill-x17-feasibility.html (slide 4 “Verdict”). No condor jobs pending.

**Result:** n_TOF hardware + ≤3° MM segments + 20° collinearity veto (no panel) + CFRP end cap → 1.2e-2
(3σ, 50 d). Accidentals left = Be window + air only; IPC floor 6.2e-3. In ⁸Be units: ×7.5 as is, ×3.8 with
zero background, ×2.7 for the 200 ps floor. Unpolarised, one cycle cannot reach ⁸Be's level.

**Follow-ups (none started):**
1. Theory: ask Viviani et al. for X17/γ at E_n ≈ 25 meV (hindered thermal M1 decides above/below ⁸Be).
2. Polarised ³He at PF1B (Tyrex-type cell + polarised beam): E0 suppression and J^π. Cell compatibility,
   polarisation, lifetime in beam.
3. Simulate the levers in `ill/sim/lxplus/conservative.py --budget`: an E0-removed oracle (floor ÷ ~1.6
   estimate) and an efficiency/containment scan (×4 containment → ÷ ~2 estimate).

**Gotchas:** local `python3` has no pandas; build the deck with
`~/PycharmProjects/nTof_x17/.venv/bin/python ill/deck/build_deck.py`. Publish with
`python3 ~/PycharmProjects/dylan-cern-site/scripts/add-note.py ill/out/feasibility_deck.html --slug ill-x17-feasibility --force --deploy`.
Heavy work only as condor jobs; C1w jobs need ~14 GB. Scripts run from `/afs/cern.ch/work/d/dneff/git/x17_ill/analysis/`.

## trigger_scint — big-slab backgrounds at the ILL — updated 2026-10-02 (dylan-MS-7C84)

**Goal:** decide whether a large, thick (H-rich) trigger slab drowns the ILL
pair search in background, compared with the detector as built (P2 70×70×2,
P5 75×75×5, P5L/P5B = P5 + 2 mm ⁶LiF/B₄C wrap). The answer goes in
`trigger_scint/BACKGROUNDS.md`. Full run log: `trigger_scint/STATUS.md`
("Session 2" and "Session 2 restart").

**Done:**
- All TB Geant4 runs finished. Analysis done for asbuilt (air ×1, ×0.1) and P2.
  JSONs are in `trigger_scint/sim/bkg/`, and `bkg_figs.py` has been run on them.
- P2 result: no better than as built at Esum > 13 MeV (timing reach 1.6e-2 vs
  8.4e-3). That is expected: a 2 cm slab has as-built signal acceptance.
- Restart at 18:30: released the held P5_C1w reductions at 40 GB, and dropped
  4 truncated raw files (merged partially with `merge_partial.sh`).

**In progress / where it stopped (on lxplus926, nohup):**
- `x17_trig/pipeline_tb.sh`: P5L/P5B C1w reductions running (condor 4354874,
  4354876, 42 GB). P5_C1w reduction (4354038) has left the queue and should
  merge on the next pass.
- `x17_trig/analysis/run_bkg.sh P5 P5L P5B`: each geometry starts once its
  `.merged` markers exist and takes ~40 min. Output:
  `/eos/experiment/ntof/data/x17/ill/TB/analysis/{P5,P5L,P5B}[_air0.1].json`
  and `.log`.
- Expected done ~20:30–21:00 on 2026-10-02.

**Next steps:**
1. Check that the outputs exist. If the drivers died, restart them (commands
   in STATUS.md) and check `condor_q dneff -hold`.
2. `scp lxplus:/eos/experiment/ntof/data/x17/ill/TB/analysis/P5*.json trigger_scint/sim/bkg/`,
   then run `python trigger_scint/bkg_figs.py`.
3. Compare P2/P5/P5L/P5B with as built: reach vs gate G, trigger rates, MM
   occupancy, budget.
4. Write `trigger_scint/BACKGROUNDS.md`. Include the unsimulated hall-γ
   caveat (STATUS.md). Update README and the TRIGGER_OPTIONS recommendation,
   then log it on the x17 board.

**Gotchas / decisions:**
- C1w reductions need ~36 GB. The pipeline now asks 40 GB.
- The truncated raw files (P5_C1 job008, P5_K1 jobs 003/024/032) were not
  rerun. The merge normalises by summed N.sim, so they cost statistics only.
  `pipeline_tb.sh` keeps looping on those two directories, which is harmless.
- `lxplus989` and `lxplus926` can't be reached by name (host key); use `ssh lxplus` and work from AFS.

**Key files & commands:**
- `trigger_scint/bkg_reach.py` — reach model with pile-up (runs on lxplus).
- `trigger_scint/bkg_figs.py` — figures and tables from `sim/bkg/*.json`.
- `trigger_scint/sim/lxplus/{submit_tb,pipeline_tb,merge_partial,run_bkg}.sh` — copies of the lxplus drivers.

## ILL rate vs DREAM dead time — updated 2026-10-02 (dylan-MS-7C84)

**Goal:** check whether the DREAM DAQ, which reads full Micromegas waveforms for the
TPC tracking, limits the usable ILL absorbed rate. Dylan feared it would change
the reach by orders of magnitude.

**Done (analysis only; no change to the feasibility code yet):**
- **DREAM limits**, from `~/PycharmProjects/nTof_x17_DAQ/docs/REPORT_2026-07-28_pulser_daq_characterization.md`,
  `DAQ_OPTIMIZATION_SUMMARY_2026-07-23.md`, `CLOCK_RATE_SCAN_2026-07-23.md`,
  `CLOCK_WINDOW_RESULT_2026-07-24.md` and `METHOD_readout_window_optimization.md`:
  - The ceiling is ~83 MB/s **per FEU**, wire-limited. It is not set by IPD, host, network or disk.
  - RAW production point (20 samples × 60 ns = 1.2 µs, Hwm 1): **3.35 kHz max, τ ≈ 298 µs** per event.
    Readout is non-paralysable, one event at a time, so live = 1/(1 + f·τ).
  - τ scales linearly with the number of samples.
  - ZS reached 10.8 kHz at 32 samples on the pulser. ZS at real occupancy is unmeasured, and the
    `PedSub` double-subtraction question is still open.
  - The 20-sample window holds 95 % of the drift charge at 700 V drift.
- **Trigger rate per 10¹⁰ absorbed n/s**, G5 tables, from `ill/sim/trig_ladder.py`:

  | trigger | rate | X17 kept |
  |---|---|---|
  | bare SiPM 0.5 MIP, both arms | 5.6 kHz | 100 % |
  | + ≥ 1 plastic (n_TOF-like menu) | ~1.1 kHz | 99 % |
  | + plastic in both arms | ~110 Hz | 66 % |
  | arm energy > 1 MeV, each arm | 1.2 kHz | 95 % |
  | arm energy > 2 MeV, each arm | ~120 Hz | 91 % |
  | sum of the two arms > 8 MeV | ≲ 110 Hz | 100 % |

- **Live fraction** (cosmics ~16 Hz added):
  - 2 MeV per-arm threshold: 0.97 at 0.9e10 n/s, 0.93 at 1.9e10, with the 1.2 µs window.
  - Same threshold, 4.8 µs window: 0.87 and 0.78.
  - Bare SiPM trigger, 1.2 µs window: 0.40 and 0.24.
  - The n_TOF-like menu: ~0.78 at 0.9e10.
  - All fitted components scale with live time, so reach ∝ 1/√live.
- **Conclusion:** DREAM costs an O(1) factor, not orders of magnitude, as long as the hardware
  trigger cuts on arm energy at ~2 MeV.
  - With that cut: ~2 % in reach (1.2 µs window), ~7 % (4.8 µs).
  - Worst case, a bare trigger at 1.2 µs: ~×1.6 in reach.

**In progress / where it stopped:** answered in chat; not yet written into `ill/FEASIBILITY_SIM.md`.
That file and `ill/README.md` have uncommitted edits from another session, so they were left untouched.
Open question to Dylan: what drift window the ILL TPC needs (the study only went to 4.8 µs).

**Next steps:**
1. Add a DREAM live-time factor to `ill/sim_feasibility.py` `model()`: τ = 298 µs × n_samples/20,
   trigger rate per absorbed n from the menu. Then re-optimise the rate and redo `scan_v1`.
2. Run a larger **unbiased** C1 sample on lxplus to measure the trigger rate above 2 MeV per arm.
   It currently rests on one unit-weight Monte Carlo row.
3. In `ill/ill_rates.py`, set `DREAM_MAX_HZ` from 1e3 to the measured 3.35 kHz (RAW, 20 samples),
   scaled by n_samples.
4. Write it up as a new §10 in `FEASIBILITY_SIM.md`, plus a slide in the deck (`ill/deck/build_deck.py`).

**Gotchas / decisions:**
- The 5.5 kHz in FEASIBILITY_SIM §2 is the SiPM-only menu. It is not a realistic ILL trigger.
- A plastic-in-both-arms trigger loses 34 % of X17, because the leptons often miss the plastic.
  Use arm energy (sum of the arm's scintillators) or a two-arm sum instead.
- The ILL hall's ambient γ and fast-neutron rate is unknown (`ill/FACILITY.md`). It could raise the
  low-threshold singles above the Monte Carlo.

**Key files & commands:**
- `cd ill && PYTHONPATH=. python sim/trig_ladder.py` — the trigger ladder (uses local
  `sim/contracts/C1_G5` and `sim/s1test/G5_X17`)
- `ill/sim_feasibility.py` — reach model (no DAQ live time yet)
- `ill/beam_spot.py` — beam rate vs spot diameter (Ø2 cm ≈ 1.9e10 n/s)

## he4_bag — ³He cell skin choice (Al foil) — updated 2026-10-02 (dylan-MS-7C84)

**Goal:** choose a 1 bar ³He cell skin that stops ³He permeation without adding neutron-capture
background or lepton scattering. Dylan's questions: alternatives to Al, the thinnest foil, what the
scattering "base" is, and whether 1 bar needs any strength.

**Done (analytic; published):**
- `he4_bag/he4_bag.py` §6 (metals, foil_gauge, chord_budget, hoop) → `he4_bag/out/{metals,foil_gauge,chord_budget,chord_ladder,hoop}.csv`.
- Slides 11–15 added to the note, republished at https://dylan-neff.web.cern.ch/notes/ill-he4-bag-3he-leak.html.
- `he4_bag/README.md` §6; pointers in `ill/FEASIBILITY_SIM.md` §5 and §9, `ill/README.md`, and the `vessel_design/mylar_wrap_vessel.py` docstring.
- Results:
  - The skin is already outside the beam (R 40 mm vs r99 12.9 mm) and adds ~1e-8 captures/n.
  - The Al that matters is the 8 mm end caps: upstream cap + ring are in 63 % of G1 accidentals.
  - Al is the right metal (only Be is better, and it can't be wrapped).
  - Skin: 12 µm PET + 6–7 µm converter foil, no PE sealant.
  - Scattering base: Micromegas 9 µm Cu 39 %, air 33 %, skin 8 %.
  - ±50 mbar is fine with the PET as the load layer. The cell can't be pumped out to fill it.

**Next steps:**
1. Geant4 (ILL branch of MX17_Full_Geant, lxplus): run C1 on G1 with the laminate skin. This needs a
   two-layer `--skin`; `Al:0.007` alone gives a bound.
2. Geant4: run G1 with the upstream Al cap lined with ⁶LiF, or trimmed, then rerun `ill/sim/lxplus/acc_sources.py`.
3. Check that the 9 µm Cu in the Micromegas entrance is the drift cathode, and whether it can be aluminised.
4. Bench-leak-test a short PET/Al prototype with a He leak detector.

**Gotchas / decisions:**
- Pinhole densities, thinnest foils and yields are catalogue-level (order of magnitude). The barrel
  crossing rate (1e-4/n) is analytic.
- Neither run is set up yet.

**Key files & commands:**
- `python3 he4_bag/he4_bag.py && python3 he4_bag/make_he4_bag_deck.py`
- `python3 ~/PycharmProjects/dylan-cern-site/scripts/add-note.py he4_bag/out/he4_bag_deck.html --slug ill-he4-bag-3he-leak --force --deploy`

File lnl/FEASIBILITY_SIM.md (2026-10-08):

# LNL ⁸Be with MX17: the Geant4 feasibility

Written 2026-10-08, from the overnight Geant4 campaign on the MX17_Full_Geant `lnl`
branch. This replaces the detector half of `ESTIMATES.md`: the toy acceptance ×
`EPS_REST`, the γ₁ "leak" and the borrowed ILL cosmic rate. The physics weights are
unchanged: cross sections, yields, the direct/resonant split and the IPC α all come
from `lnl_rates.py` (`out/yields.csv`, `out/ipc_alpha.csv`).

Code: `sim/lnl_geant.py`. Outputs: `out/geant/*.csv` and `out/geant/figures/`.
The lxplus reduction is in `sim/lxplus/`.

---

## 0. Bottom line

1. **As built, the n_TOF hardware reaches the ATOMKI ratio at 3σ in about 2–3 weeks
   at 1 µA**, provided the cosmics are killed by either of two cuts:
   - Micromegas segments good to ≲ 3°;
   - a ~0.3 ns time-of-flight cut between the arms.

   This is the same as the pre-Geant4 guess (15 d), but for different reasons:
   - The signal acceptance is **2.4× lower than the toy**.
   - The **energy sum separates the 15 MeV (γ₁) IPC almost completely**, which the
     toy did not assume.

   | 1 µA, Li₂O 300 µg/cm² at 1.10 MeV | counting, best window | template fit (IPC norm free) |
   |---|---|---|
   | as built, LS working | **15 d** | 22–24 d |
   | as built, LS off | 19 d | 25 d |
   | **big plastics (4 × 75×75×5 cm), all 20 SiPM bars** | **1.0–1.2 d** | **1.4–1.6 d** |

2. **The four big plastics are worth ×13–15 in running time.**
   - The trigger acceptance goes from 3.3 % to 23 % of X17 pairs (×7).
   - 5 cm of plastic is a calorimeter: 15 and 18 MeV transitions land 3 MeV apart
     (§3).
   - At CN's 4 µA, a 3σ test of ATOMKI takes **hours**, and the 0.8 / 1.225 MeV
     off-resonance points (ATOMKI 2022, Hanoi) take ~1 day each.
3. **Cosmics are the only background that can sink the as-built setup.**
   - Without vetoes, ~8×10⁴/day pass into 125–155°, against ~120 IPC/day after the
     same cuts (§4).
   - An E_sum *window* (13–17 MeV) works only if the LS work; muons leave 20–35 MeV.
   - **15° segments (the chambers as measured) do not stop them. 3° segments or TOF
     do**: with the E_sum window, either brings them to ~1/day; together, to 0 in a
     live day.
   - This is MEG II's 2026 point about ATOMKI, now quantified for MX17.
4. **Everything else is small:**
   - EPC from the target region: ≤ 10⁻² of the IPC in the window.
   - Accidentals: ≲ 0.02/day.
   - DREAM dead time: 3.5 (as built) or 22 (big plastics) two-arm triggers/s, from
     cosmics. That means < 1 % dead.
   - The 478 keV ⁷Li line never makes a leg.
5. **Material.**
   - The chamber wall sets the opening-angle resolution: CFRP 0.4 mm gives 5.1°,
     Al 0.5 mm 8.8°, Al 1 mm 12.2°.
   - A Cu backing costs 2.4° over Al/C.
   - Acceptance does not change.
   - **Keep the CFRP chamber and a low-Z backing.**

## 1. Runs (2026-10-08, lxplus condor)

All runs use the `--target li` baseline:
- Li₂O 300 µg/cm² on Al 10 µm;
- Al 1 mm holder annulus;
- CFRP 0.4 mm chamber of bore 25 mm;
- Ta 2 mm dump;
- σ_spot = 2 mm;
- n_TOF arms at the surveyed positions.

Binaries:
- `bin/mx17_full_sim_lnl_079db11` for L1/L2 as built;
- `bin/mx17_full_sim_lnl_a424eed` for everything else. It is the `lnl` branch with
  `trigger_plastics` merged; the physics is identical.

Outputs are in `/eos/experiment/ntof/data/x17/lnl/<run>/<sample>/`.

| run | samples | events | notes |
|---|---|---|---|
| L1 | X17 at W = 18.15, m = 16.6 / 16.7 / 16.8 / 17.0 | 10⁶ each | |
| L2 | Born IPC M1/E1 at 18.15, M1 at 17.64, M1/E1 at 15.1 and 14.6 | 10⁶ each | |
| L1/L2 `_bigP` | the same with `--big-plastic 75 75 5 --no-ls --sipm-readout 20 0` | 10⁶ each | the trigger_scint calorimeter option |
| L1/L2 `_sipm20` | X17 16.7/17.0 and the 18.15/17.64/15.1 IPC, with all 20 SiPM bars read | 10⁶ each | |
| L3 | γ lines from the spot: 8Be (18.15, 17.64, 15.1, 14.6), ¹⁹F (6.13, 6.92, 7.12), ⁷Li 0.478, ²⁸Si 10.76 + 1.78 | 2.1×10⁸ 8Be γ as built, 1.1×10⁸ big plastics; 5×10⁶ each other set | EPC, singles, accidentals |
| L4 | cosmic μ (3×3 m plane, 1 /cm²/min, zenith ⊥ beam), as built and big plastics | 1.3×10⁸ each = 1.00 live day | |
| L5 | X17 16.7 and M1 18.15 with chamber Al 0.5 / Al 1.0 mm, backing C 20 µm / Cu 25 µm | 5×10⁵ each | |
| L6 | E0 IPC at 6.05 MeV (¹⁶O 0⁺₂, the LiF calibration line) | 10⁶ | |

**Reduction** (`sim/lxplus/`, all on condor):
- `lnl_reduce.py`: per file, `ill_pairs.py` reduce + the ILL `seg_reduce.py`.
- `lnl_time.py`: earliest SiPM-wall and plastic time per arm.
- `lnl_merge.py`: one compact table per sample.
- `lnl_pipe.sh` drives them; it is idempotent.

Copy the tables locally with `sim/fetch_sel.sh` (gitignored `sim/sel/`).

## 2. Selection, data-like

Nothing uses Monte Carlo truth to select.
- **Ok arm:**
  - a trigger leg in that arm: a SiPM bar AND a plastic, each ≥ 0.5 MIP, the
    thermal_accounting definition;
  - a Micromegas dominant-track segment (≥ 3 steps);
  - its charge centroid in the active area (|along beam| < 180 mm, |transverse −
    pinwheel shift| < 199.7 mm).
- **Pair:** ≥ 2 ok arms; the two with the most scintillator energy.
- **Opening angle:** the chord from the beam spot (0,0,0) to the two MM charge centroids.
  - Resolution for the X17: **σ68 = 5.3°, bias +0.5°**.
  - The arm choice matches the true lepton arms in 99.8 % of events.
- **E_sum:** SiPM + plastic + LS energy of the two arms, in a window [E_lo, E_hi].
  - The window is chosen per hardware and analysis level on the reference setting.
  - In "LS off", the LS energy is dropped.
- **Analysis levels:**
  - **trigger:** nothing more.
  - **MM 15° / MM 3°:**
    - each segment, with its direction smeared by 15° (the measured chambers:
      11–26°) or 3° (the ILL upgrade scenario), must point back to the spot within
      D;
    - D keeps 90 % of X17 segments per arm (135 mm at 15°, 57 mm at 3°; at 3°,
      scattering in the window and gas dominates);
    - plus a 20° collinearity veto on the two segments.
  - **+ TOF:** each arm's earliest SiPM-wall time, smeared by σ_t = 0.3 ns.
    - A pair is vetoed if the lower arm fires > 2√2 σ_t = 0.85 ns after the upper
      arm (|Δt| for arms at the same height).
    - X17: |Δt| < 0.15 ns (95 %).
    - Cosmics: the lower arm fires 2.3 ns later (median).
    - **σ_t = 0.3 ns is an assumption (ask):** what the n_TOF SiPM wall achieves
      with its digitiser is not documented here.
- **Reach:**
  - **Counting** in the window that maximises S/√B (typically 130–165°).
  - **Asimov template fit** over 90–180° in 2° bins:
    - IPC normalisation and γ₁ free, M1/E1 mix fixed: "fit, 1 norm";
    - or M1, E1 and γ₁ all free: "fit, 3 norms", in `reach_geant.csv`.
  - Background templates are smoothed with a 5° Gaussian KDE: the IPC samples leave
    only 10–200 MC events per 10° above 90°, and empty bins would fake infinite
    sensitivity.
  - Days are scaled to 3σ at R = 5.8×10⁻⁶ and divided by the DREAM live fraction.

## 3. Acceptance and energy

`out/geant/acceptance_geant.csv`, `figures/geant_chain.png`, `figures/geant_esum.png`.

| X17 m = 16.7 at 18.15 MeV | as built | 20 SiPM bars | big plastics |
|---|---|---|---|
| both leptons in the MM active area, different arms | 38.7 % | 38.8 % | 38.8 % |
| + a trigger leg in both arms (pair-tag) | **3.3 %** | 3.3 % | **23.2 %** |
| + E_sum window, + MM 15° + TOF, in 125–155° | 0.7 % | 1.2 % | **10.9 %** |

- **The toy was right about geometry:** 39 % against 45 %, the toy having no
  active-area cut.
- **The toy was wrong about what follows.**
  - The ILL `EPS_REST` = 0.14 was really 0.084 here (pair-tag over MM).
  - The four-arm geometry favours back-to-back pairs, so the accepted X17 spreads to
    170°. Only 64 % of the tagged pairs fall in 125–155°.
- **Reading all 20 SiPM bars buys nothing as built.** The two 20 × 30 cm plastics are
  the bottleneck (trigger_scint §1). With the big plastics, all 20 bars are used.
- **E_sum separates 15 from 18 MeV.**
  - **As built (with LS):** the 18.15 MeV pairs (X17 and IPC) peak at 14–15 MeV, and
    the 15.1 MeV IPC at 11–12 MeV with nothing above 13. A 13–16/17 MeV window keeps
    54 % of the X17 and removes the γ₁ IPC to < 0.5/day.
  - **LS off:** the peaks merge at 8–10 MeV and γ₁ stays in full.
  - **Big plastics:** sharp peaks at 15.3 and 12.3 MeV. A 13–17 MeV window keeps 83 %
    of X17 and 1.5 % of γ₁.
- **The mass scan** (`reach_geant.csv`): acceptance rises from m = 16.6 to 17.0 (3.1 →
  4.0 % pair-tag as built) because the edge moves to larger angles. Days to 3σ:
  16.7 → 16 d, 17.0 → 8.5 d as built; 1.2 → 0.9 d with the big plastics.

## 4. Backgrounds other than IPC

**Cosmics** (L4, one live day, `out/geant/cosmics_*.csv`). Pairs in 125–155° per day,
as built:

| level | no E_sum cut | E_sum 13–17 (LS on) | E_sum 8–16 (LS off) | big plastics, 13–17 |
|---|---|---|---|---|
| trigger | 82,000 | 3,700 | 71,000 | 460 |
| MM 15° (+20° coll.) | 14,600 | 570 | 12,600 | 61 |
| MM 3° | 41 | 1 | 37 | 2 |
| MM 15° + TOF | 10 | 1 | 7 | 0 |
| MM 3° + TOF | 0 | 0 | 0 | 0 |

One live day: the entries of 0–2 are single events (±100 %). The reach uses a smoothed
template scaled to max(n, 1) per day.

- The cosmic two-arm events have E_sum 20–34 MeV with the LS (median 26).
- **The upper edge of the E_sum window is the cheapest cut.**
- The 20° collinearity veto is ineffective at 15° segment resolution: two smeared
  segments of one straight muon differ by ~20° anyway.
- With the big plastics (5 cm), muons leave ~10 MeV per arm, and the 13–17 MeV
  window alone removes 99.8 %. With MM 15° + TOF, < 1/day remains, against 1,480 IPC/day.

**EPC and Compton from the target region** (L3, 5×10⁷ γ per line as built):
- per γ of 18.15 MeV, 3×10⁻⁶ two-arm events pass, all at 25–92° (adjacent arms);
- **none in 125–155° in 5×10⁷ γ** (< 6×10⁻⁸ per γ, against ~10⁻⁶ per γ for IPC in
  the window).
- With the big plastics (2.75×10⁷ γ per line), a few events land in the window:
  ~4×10⁻⁸ per γ after E_sum 13–18, ~10/day, < 1 % of the 1,480 IPC/day.

**Singles, accidentals, DAQ** (`out/geant/daq_load.csv`):
- Per 8Be γ: 0.39 % make a leg in some arm, and 0.04 % per arm are "ok" (leg + MM).
- At ATOMKI conditions (~6×10³ γ/s at 1 µA), each arm sees ~9–22 legs/s, the top and
  bottom arms mostly from cosmics.
- Two-arm hardware triggers are **3.5/s** as built and **22/s** with the big
  plastics. Both are cosmic-dominated; the beam adds < 0.3/s.
- DREAM at 298 µs → live ≥ 99 %.
- Accidental pairs with 2τ = 20 ns: ≲ 0.02/day in the window.
- **The other γ sources:**
  - ⁷Li(p,p′) 0.478 MeV: 5×10⁶ γ, **no leg**.
  - ²⁸Si 10.76 MeV, from ²⁷Al(p,γ) at the 992 keV resonance, when an Al backing is
    crossed at E_p > 992 keV: 0.36 % legs per γ, like the 8Be lines, at ~3× the γ₀
    rate. It is harmless after the E_sum window (its pairs have ≤ 10.8 MeV).
  - ¹⁹F lines (LiF targets): 0.3 % legs per γ, no two-arm events in 5×10⁶. **They
    matter only through singles:** at 10⁵–10⁶ γ/s (a LiF target crossing a strong
    ¹⁹F(p,αγ) resonance), legs reach 10²–10³/s per arm. Use Li₂O.

## 5. Material (L5)

`out/geant/material_scan.csv`, MM 15°:

| | X17 σ68(Δθ) | M1 σ68 | X17 acc (two-arm, MM 15°) |
|---|---|---|---|
| baseline: CFRP 0.4 mm chamber, Al 10 µm backing | **5.1°** | 6.6° | 2.09 % |
| Al 0.5 mm chamber | 8.8° | 12.6° | 2.12 % |
| Al 1.0 mm chamber | 12.2° | 17.6° | 2.16 % |
| C 20 µm backing | 5.1° | 6.2° | 2.08 % |
| Cu 25 µm backing | 7.5° | 11.7° | 2.10 % |

The resolution sets how sharp the X17 edge at 134–139° is. It matters for the mass and
for any IPC-shape systematic. **CFRP chamber, Al or C backing.**

## 6. What the trigger cannot see

- **The E0 6.05 MeV calibration line** (L6, ¹⁶O 0⁺₂ from F or O): **0 pair-tags in
  10⁶ pairs**, as built. The ~2.5 MeV leptons do not reach 0.5 MIP in both the SiPM
  bar and the 2 cm plastic behind ~2 g/cm² of MM stack.
- The 441 keV (17.64 MeV) M1 line *is* visible (L2 M1_17.64: same acceptance as
  18.15). It is the calibration point of choice.

## 7. Caveats

- **The LS energy.** The as-built E_sum, and so the as-built cosmic rejection, assume
  the LS work. At n_TOF they suffered pile-up (67–76 % of pulses). At LNL the rates
  are 10³× lower, so they should, but this was never shown. Without LS, the as-built
  setup needs the 3° segments or TOF *and* loses the γ₁ separation: 19 d instead of
  15 d.
- **TOF σ_t = 0.3 ns** is assumed (ask). The scan below is cosmics per day in 125–155°
  after MM 15° + E_sum 13–17 + TOF (cut at 2√2 σ_t), with the X17 efficiency of the TOF cut:

  | σ_t per arm | 0.2 ns | 0.3 | 0.5 | 0.7 | 1.0 | 1.5 |
  |---|---|---|---|---|---|---|
  | as built (MM 15° alone: 569) | 1 | 1 | 53 | 189 | 350 | 465 |
  | big plastics (MM 15° alone: 61) | 0 | 0 | 3 | 22 | 39 | 52 |
  | X17 efficiency of the cut | 0.96 | 0.97 | 0.97 | 0.97 | 0.97 | 0.97 |

  As built, TOF needs **σ_t ≲ 0.4 ns**: at 0.5 ns, 53 cosmics/day remain against ~110 IPC
  (~+25 % in time). At ≥ 1 ns it does little, and the 3° segments are needed.
- **IPC shapes are Born M1 and E1 without interference**, with the M1/E1 mix fixed by
  the Zahnow decomposition.
  - If the fit has to learn the mix (M1, E1, γ₁ all free), the days go up ×2.3–3
    (`days_fisher_live`). The accepted E1 IPC has its own hump at 140–170°, from the
    back-to-back geometry.
  - A measured off-resonance E1 shape (0.8 MeV runs) or the Zhang–Miller generator
    fixes this.
- **Cosmic flux:** 1 /cm²/min, sea-level vertical, no building overburden. LNL is at
  sea level; the hall roof would lower it slightly.
- **σ68 counts the MM centroid only.** A per-event vertex (two-track crossing) is not
  needed at LNL: the spot is σ = 2 mm.
- Not simulated: ¹¹B contamination (16 MeV γ, `TARGETS.md`), beam halo on the
  holder/flanges, and the beam pipe beyond the chamber.

## 8. Next

1. **Ask the collaboration:** the SiPM-wall time resolution in the n_TOF DAQ, and
   whether the LS can be read at LNL.
2. **Run the ATOMKI demonstrator data** through the same selection, if the test
   recorded MM + scintillators.
3. If the big plastics are bought: a T2 run at the final size, and the L4 cosmics
   with the real frame.
4. The Zhang–Miller IPC generator (M1–E1 interference) for the template systematic.
5. **The PAC case: with the big plastics, a week of AN2000 or a few days of CN covers
   the resonance, both off-resonance points and the 441 keV calibration.**

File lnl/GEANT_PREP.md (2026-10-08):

# Getting to useful Geant4 runs for LNL

Written 2026-10-07, for the session after the slides.

## 0. Status (2026-10-08)

**Done overnight 2026-10-08: L1–L6, the big-plastic and 20-bar variants, timing. Results in
`FEASIBILITY_SIM.md`; analysis `sim/lnl_geant.py`; pipeline `sim/lxplus/lnl_pipe.sh`.**

**Built: §2a–c** on MX17_Full_Geant branch **`lnl`** (from `ill_ring`; commits 5722bef, 1577274, 079db11, pushed).
- `--target li` with `--film Li2O|LiF|Li:ug_cm2`, `--backing Mat:um|none`, `--holder Mat:mm|none`,
  `--holder-r rin:rout`, `--chamber Mat:t_mm:r_mm`, `--chamber-len`, `--flange Mat:mm`,
  `--dump Mat:mm|none`, `--dump-dist`, `--spot-sigma`. Defaults = the §4 baseline:
  Li₂O 300 µg/cm² (1.49 µm) on Al 10 µm, Al 1 mm holder annulus r 10–20 mm, CFRP 0.4 mm chamber of bore
  25 mm, |y| ≤ 300 mm, Al 5 mm flanges (upstream hole r 10 mm), Ta 2 mm dump at y = 250 mm.
  Volumes: `LiTarget_Film/Backing/Holder`, `LiChamber_Vac/Wall/Flange`, `BeamDump`.
- Pair vertices (`--ipc`, X17) and γ vertices come from a Gaussian beam spot (σ 2 mm) uniform through the
  film depth; the film's downstream face is y = 0. Neither the beam pipe upstream of the flange nor the
  hall is modelled.
- `--gamma-lines E:w,...` (event_type 3, `inv_mass` = E_γ). `ConvPairTree` is now filled in these runs
  too, for the EPC.
- Driver: `scripts/submit_lnl.py --run Lk --sample X17_m16.7 | M1_18.15 | gam_8Be | cosmic`.
  Reduce with the ILL scripts unchanged: `scripts/submit_reduce_ill.py <dir> --kind pairs`, then
  `ill_pairs.py merge parts/*.npz -o <out> --config lnl` (the assumed vertex (0,0,0) is the beam spot).
- lxplus clone: `/afs/cern.ch/work/d/dneff/git/x17_lnl/{MX17_Full_Geant,MX17_Geant}` (separate from
  `x17_ill`, which is detached with local edits). Frozen binary `bin/mx17_full_sim_lnl_079db11`.

**L0 smoke (done, `/eos/experiment/ntof/data/x17/lnl/L0/`):** no overlaps (217 volumes checked);
vertices in y ∈ [−1.49 µm, 0], spot rms 2.0 mm; the X17 opening angle starts at 133.8° (θ_min for
m = 16.7 at 18.15 MeV); IPC M1 and γ-line modes run; 2000 γ give 52 conversions, in the arms and
also the holder, backing and dump. **First hint (500 X17, 18 tagged, ±25 %):** both leptons in the
MM gaps 47 % (toy: 45 %); trigger pair-tag 3.6 %. That is a post-geometry factor ~0.08 against
EPS_REST = 0.14, i.e. days ×~1.8 if L1 confirms it.

**Running (submitted 2026-10-08 ~01:00, clusters 4405805–4405815, 10 × 10⁵ each, ~20 GB per sample):**
L1 `X17_m{16.6,16.7,16.8,17.0}`; L2 `{M1,E1}_18.15`, `M1_17.64`, `{M1,E1}_15.1`, `{M1,E1}_14.6`.
Outputs `/eos/experiment/ntof/data/x17/lnl/L{1,2}/<sample>/`.

**Next:** reduce L1/L2 → acc × ε against opening angle with the per-arm trigger, and the E_sum
(SiPM + plastic + LS) spectra of 18.15 vs 15.1 MeV IPC → put the measured factor in place of
`EPS_REST` and the γ₁ leak in `lnl_rates.py`, rerun, rebuild the deck. Then L3 (`gam_8Be`, `gam_19F`)
and L4 (`cosmic`).

**The goal:** replace the four soft numbers in `ESTIMATES.md` §4 with the
simulation, in this order:
1. `EPS_REST` (trigger × E_sum × reconstruction);
2. the γ₁ separation (15 vs 18 MeV);
3. cosmics in the LNL geometry;
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

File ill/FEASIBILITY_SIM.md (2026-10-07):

# Can we measure X17 at the ILL? — what the Geant4 campaign says

2026-10-02, from the lxplus campaign in `SIM_STATUS.md` (S1, C1, C1w, C1g, K1,
S1p, S1s; all six cell configurations G1–G6). Model: `sim_feasibility.py`;
figures: `sim_report.py`; robustness: `sim_variants.py`; table:
`results/scan_v1.csv`. Outputs: `/eos/experiment/ntof/data/x17/ill/analysis/`
(local copies of the small files: `ill/sim/analysis_v3/`).
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

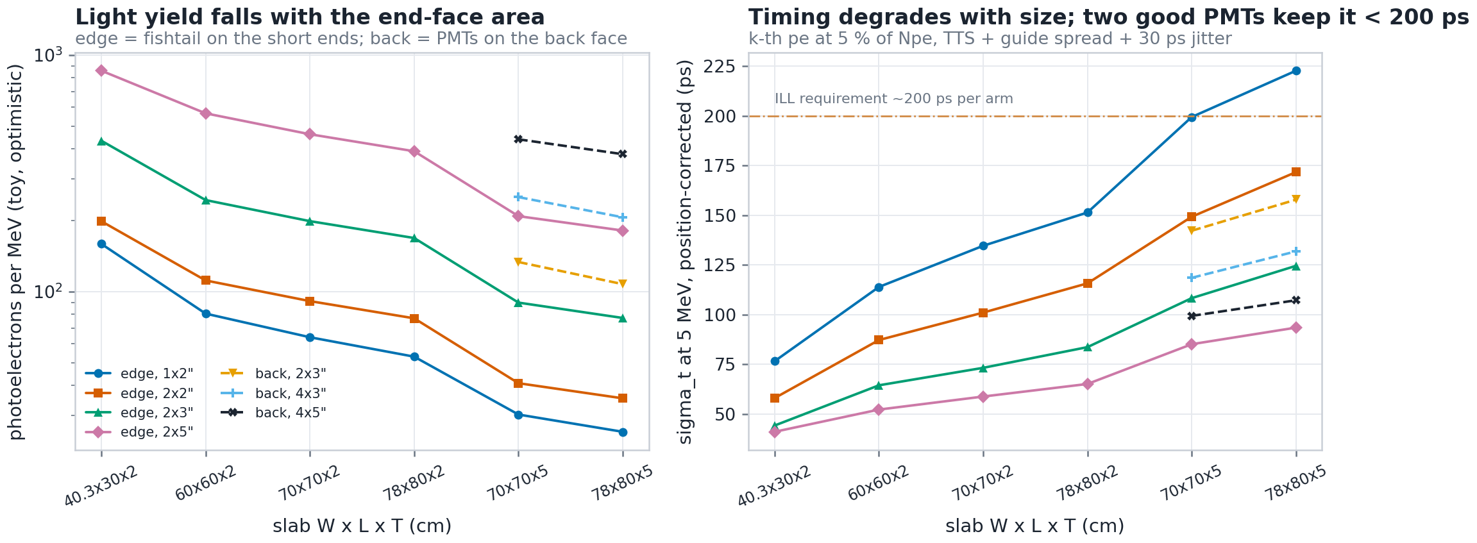
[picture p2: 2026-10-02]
trigger_scint/out/figures/optics.png

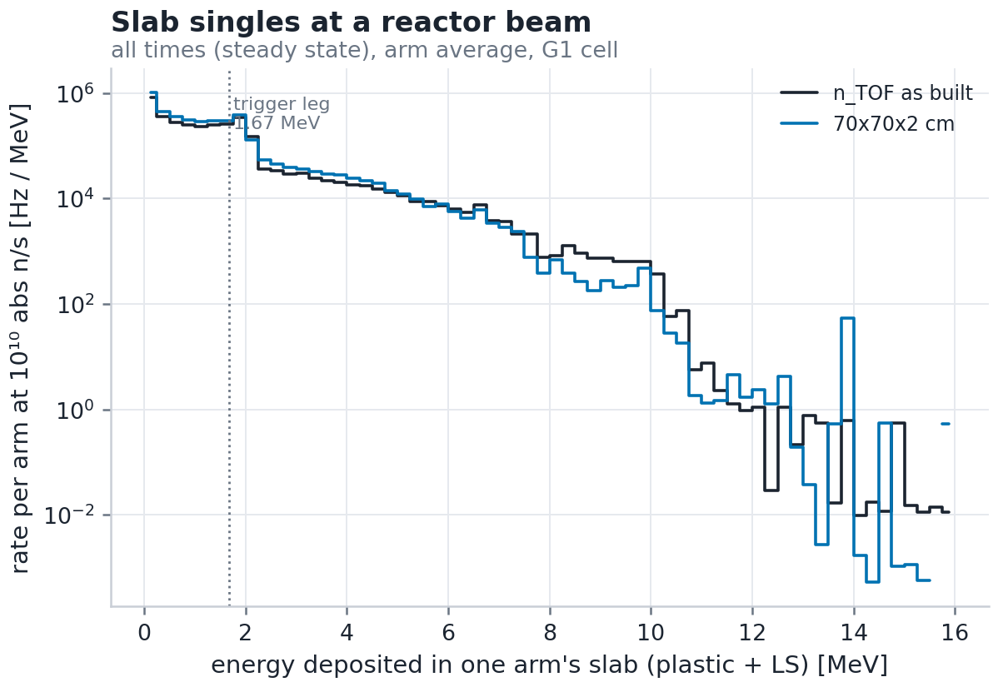
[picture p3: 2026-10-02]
trigger_scint/out/figures/bkg_singles_spectrum.png

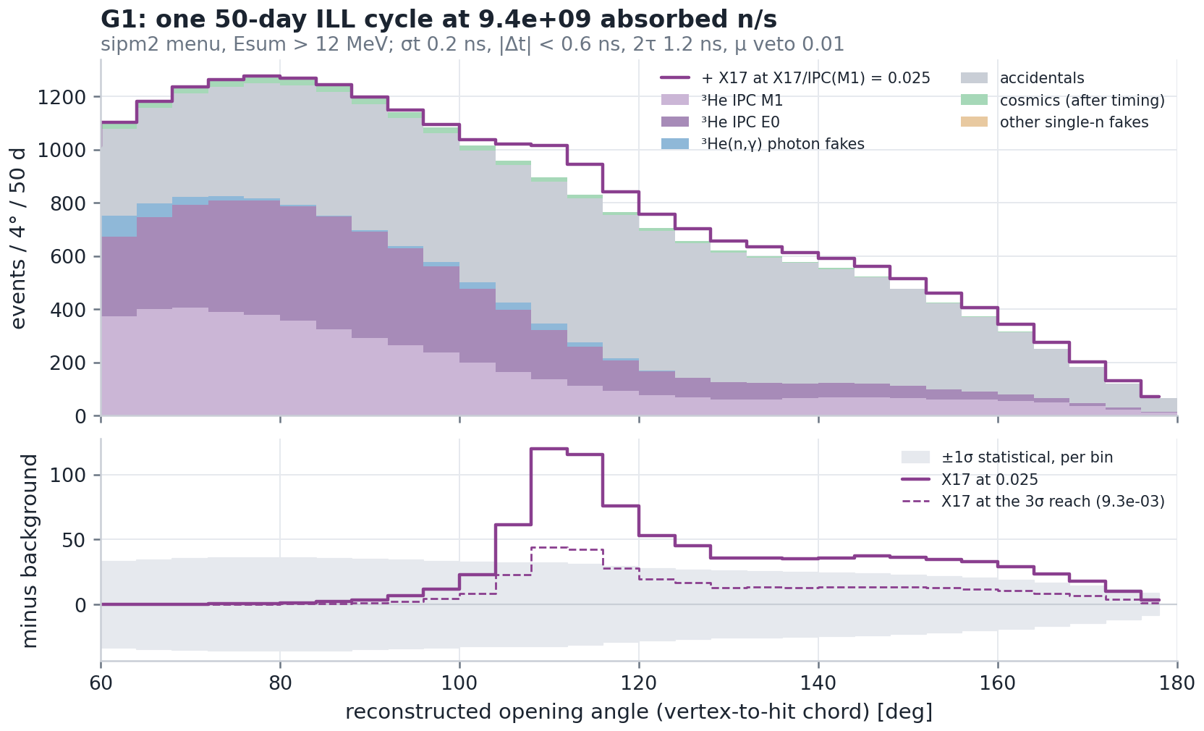
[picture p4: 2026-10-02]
ill/sim/analysis_v3/v3_timing/spectrum_G1.png

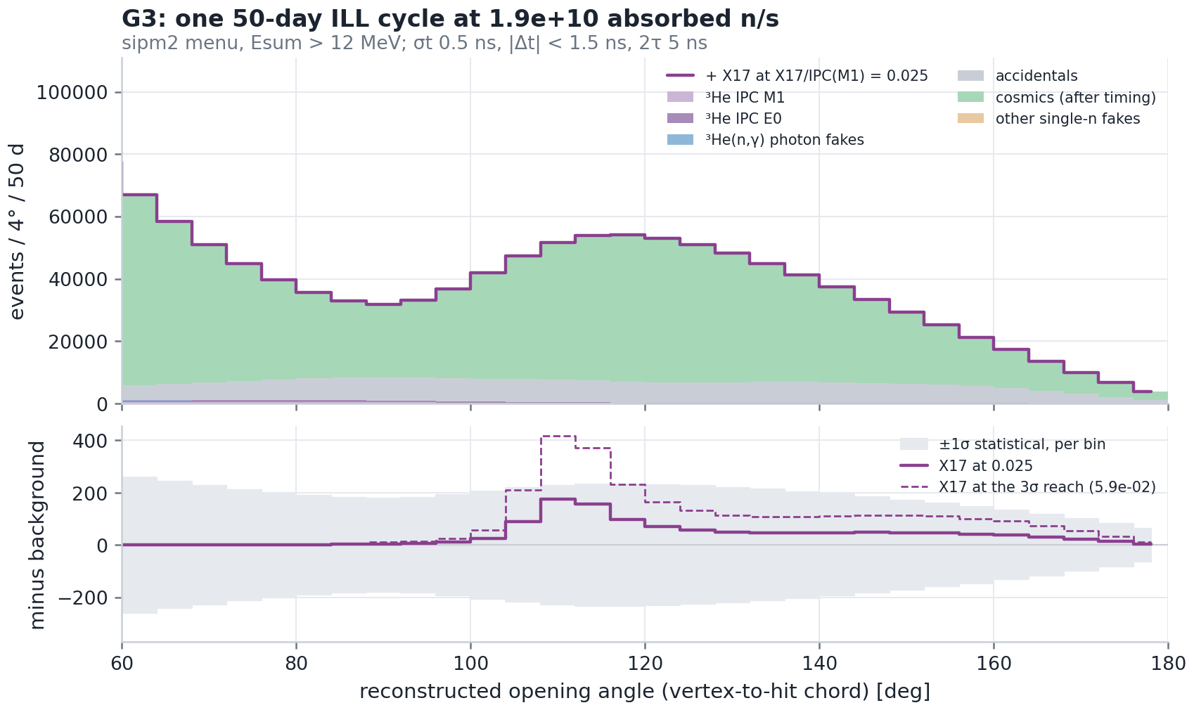
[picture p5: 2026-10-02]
ill/sim/analysis_v3/v3_base/spectrum_G3.png

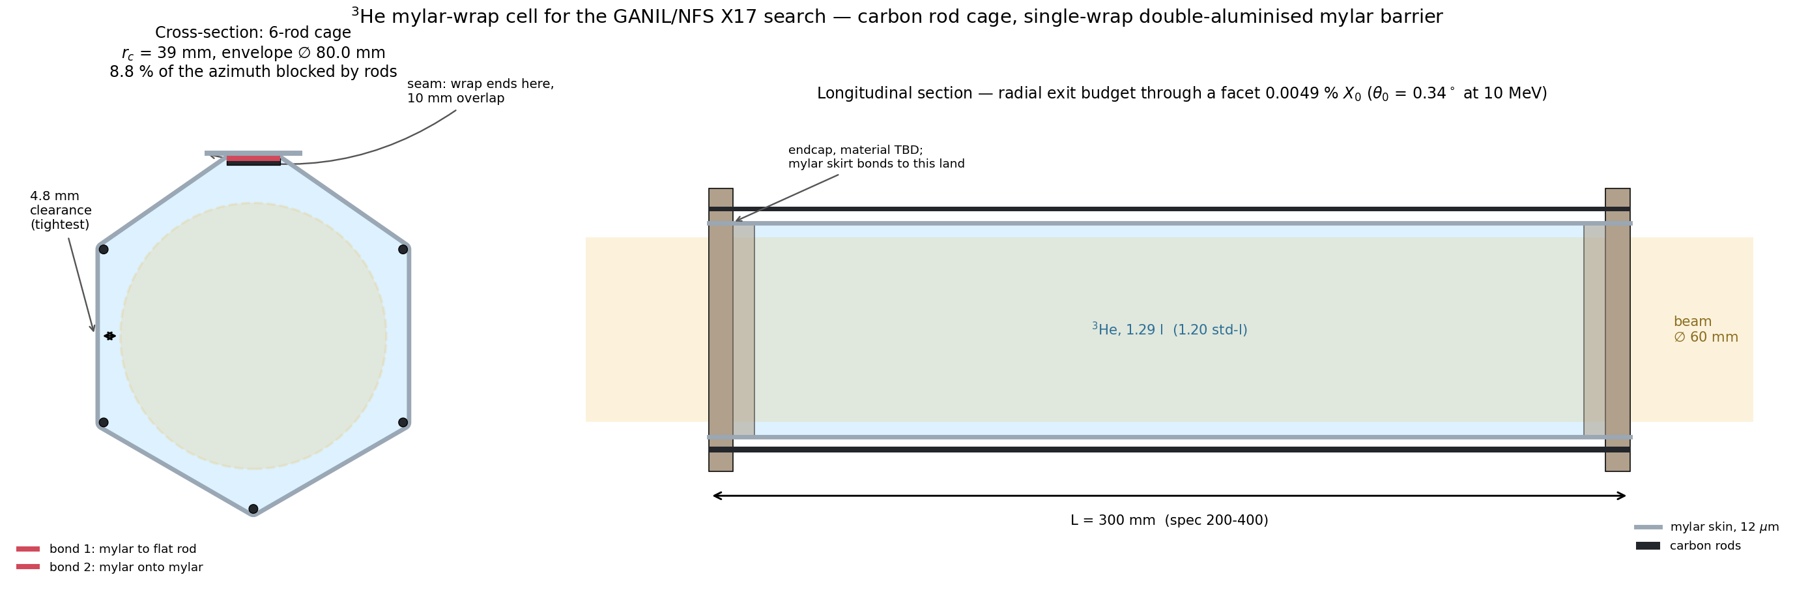
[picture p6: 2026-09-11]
vessel_design/out/sections.png

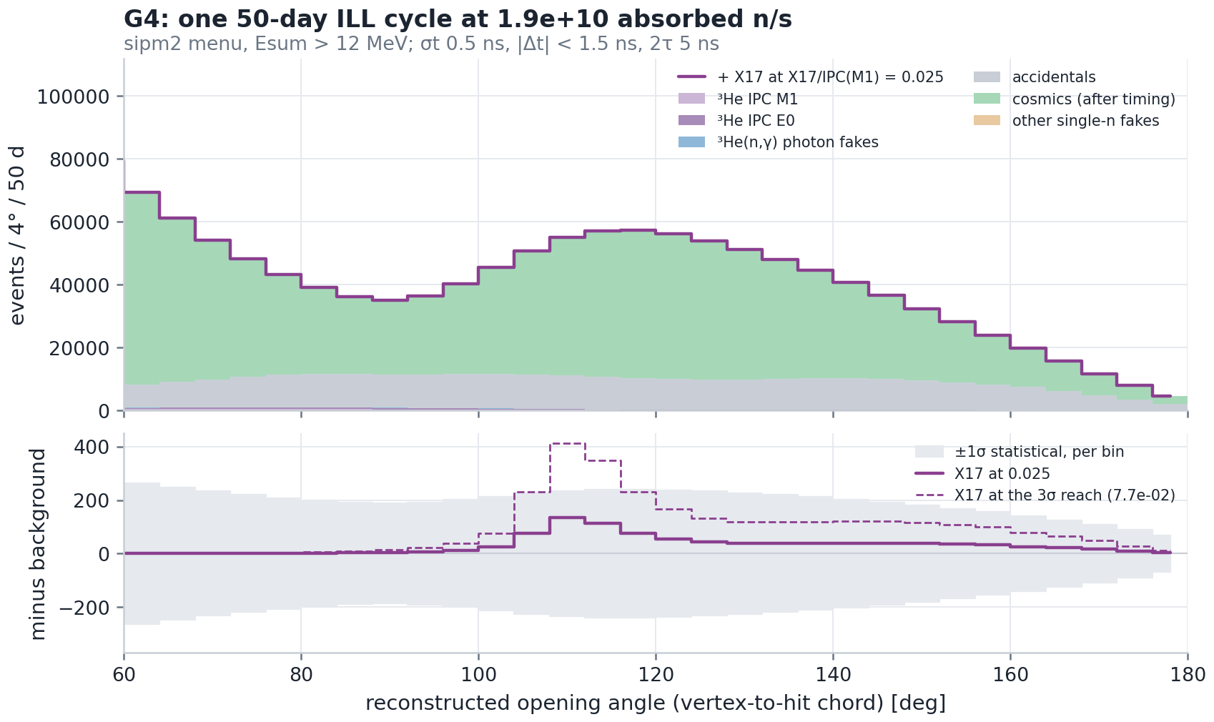
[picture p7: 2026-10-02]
ill/sim/analysis_v3/v3_base/spectrum_G4.png

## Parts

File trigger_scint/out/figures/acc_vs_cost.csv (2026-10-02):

option | kind | acc_X17 | acc_M1 | acc_X17_E13 | cost_lo | cost | cost_hi | note
n_TOF as built (16 bars ganged, 2 x 20x30x2 plastics) | baseline | 0.022992 | 0.00321 | 0.016143 | 0.0 | 0.0 | 0.0
as built + all 20 SiPM bars | baseline | 0.023174 | 0.003244 | 0.016203 | 0.0 | 0.0 | 0.0 | SiPM completion counted in the common block
LS working, LS alone as trigger | LS | 0.011896 | 0.001367 | 0.00673 | 2000.0 | 6000.0 | 12000.0
LS working, plastic OR LS | LS | 0.042655 | 0.005813 | 0.021863 | 2000.0 | 6000.0 | 12000.0
4 x 50x50x2 cm PVT, 2 x 3" PMT each | plastic 2 cm | 0.07633 | 0.010927 | 0.005445 | 35800.0 | 62000.0 | 94000.0
4 x 60x60x2 cm PVT, 2 x 3" PMT each | plastic 2 cm | 0.120115 | 0.017767 | 0.011667 | 38880.0 | 67280.0 | 102800.0
4 x 70x70x2 cm PVT, 2 x 3" PMT each | plastic 2 cm | 0.140118 | 0.020843 | 0.017259 | 45720.0 | 79120.0 | 121200.0
4 x 78x80x2 cm PVT, 2 x 2" PMT each | plastic 2 cm | 0.143636 | 0.021385 | 0.018954 | 43872.0 | 76752.0 | 121520.0
4 x 78x80x2 cm PVT, 2 x 3" PMT each | plastic 2 cm | 0.143636 | 0.021385 | 0.018954 | 49472.0 | 85552.0 | 131920.0
4 x 78x100x2 cm PVT, 2 x 3" PMT each | plastic 2 cm | 0.144336 | 0.021494 | 0.019071 | 53840.0 | 93040.0 | 144400.0
4 x 70x70x4 cm PVT, 2 x 3" PMT each | plastic 4-5 cm | 0.140845 | 0.021058 | 0.106303 | 62240.0 | 108640.0 | 170400.0
4 x 78x80x4 cm PVT, 2 x 3" PMT each | plastic 4-5 cm | 0.14443 | 0.021627 | 0.110422 | 69744.0 | 121504.0 | 191840.0
4 x 78x80x4 cm PS, 2 x 3" PMT each | plastic 4-5 cm | 0.14443 | 0.021627 | 0.110422 | 49776.0 | 86560.0 | 131936.0
4 x 70x70x5 cm PVT, 2 x 3" PMT each | plastic 4-5 cm | 0.141136 | 0.021159 | 0.120535 | 69100.0 | 120400.0 | 190000.0
4 x 78x80x5 cm PVT, 2 x 3" PMT each | plastic 4-5 cm | 0.14474 | 0.021733 | 0.124864 | 78480.0 | 136480.0 | 216800.0
4 x 78x80x5 cm PVT, 2 x 5" PMT each | plastic 4-5 cm | 0.14474 | 0.021733 | 0.124864 | 88080.0 | 146880.0 | 234400.0
4 x 78x80x5 cm PS, 2 x 3" PMT each | plastic 4-5 cm | 0.14474 | 0.021733 | 0.124864 | 53520.0 | 92800.0 | 141920.0
4 x 78x80x10 cm PVT, 2 x 5" PMT each | plastic 10 cm | 0.145893 | 0.022076 | 0.128889 | 135760.0 | 229760.0 | 371200.0

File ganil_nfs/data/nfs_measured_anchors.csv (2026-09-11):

# Measured NFS beam anchors -- every number here comes from a published measurement
# not from a model. Use these to validate any simulated NFS source.
# Columns: quantity | value | uncertainty | unit | conditions | source
quantity | value | uncertainty | unit | conditions | source
peak_differential_yield | 17.3e9 | 0.5e9 | n/uC/sr/MeV | d 40 MeV on 8 mm rotating Be, 0 deg, at E_n = 17 MeV | PavonRodriguez2025_EPJA61_277
peak_energy | 17.0 |  | MeV | energy at which the 0 deg yield peaks | PavonRodriguez2025_EPJA61_277
yield_floor_1e9_lo | 1.5 |  | MeV | lower edge of the band where Y > 1e9 n/uC/sr/MeV | PavonRodriguez2025_EPJA61_277
yield_floor_1e9_hi | 35.0 |  | MeV | upper edge of the band where Y > 1e9 n/uC/sr/MeV | PavonRodriguez2025_EPJA61_277
yield_floor_1e8_lo | 1.5 |  | MeV | lower edge of the band where Y > 1e8 n/uC/sr/MeV | PavonRodriguez2025_EPJA61_277
yield_floor_1e8_hi | 42.0 |  | MeV | upper edge of the band where Y > 1e8 n/uC/sr/MeV | PavonRodriguez2025_EPJA61_277
measured_range_lo | 1.5 |  | MeV | lowest neutron energy the 238U(n,f) monitor could reach | PavonRodriguez2025_EPJA61_277
measured_range_hi | 44.0 |  | MeV | highest neutron energy reported; yield is nonzero above the 40 MeV beam energy | PavonRodriguez2025_EPJA61_277
beam_spot_diameter | 4.44 | 0.04 | cm | at 740.6 cm from converter, 25.55 mm collimator | PavonRodriguez2025_EPJA61_277
beam_edge_falloff_10_90 | 0.49 | 0.04 | cm | same position; 10-90 percent of peak areal rate | PavonRodriguez2025_EPJA61_277
beam_divergence | 3.08e-3 | 0.07e-3 | rad | half-angle, from collimator and spot diameters | PavonRodriguez2025_EPJA61_277
solid_angle_at_740cm | 28.2e-6 | 0.5e-6 | sr | beam solid angle seen from the converter | PavonRodriguez2025_EPJA61_277
thermal_to_fast_ratio | 3.85e-5 | 0.43e-5 |  | upper limit, TOF hall, 238U(n,f) uncorrelated background | PavonRodriguez2025_EPJA61_277
total_yield_4pi | 1.8e13 |  | n/s | 40 MeV d on 8 mm Be at the 50 uA authorised maximum (0.058 n/deuteron) | Ledoux2021_EPJA57_257
flux_5m_thickBe | 5.88e6 |  | n/cm2/s | 31.9 MeV p on 8 mm Be at 50 uA, E_n > 2 MeV -- PROTONS, not deuterons | Ledoux2021_EPJA57_257
flux_5m_thinBe | 3.22e5 |  | n/cm2/s | 31.9 MeV p on 0.5 mm Be at 50 uA, E_n > 27 MeV | Ledoux2021_EPJA57_257
flux_5m_thinLi | 1.42e5 |  | n/cm2/s | 31.9 MeV p on 1.5 mm Li at 20 uA, E_n > 27 MeV | Ledoux2021_EPJA57_257
yield_thickBe_p | 29.4e9 | 4.7e9 | n/sr/uC | 31.9 MeV p on 8 mm Be, 0 deg, E_n > 2 MeV | Ledoux2021_EPJA57_257
yield_thinBe_p | 1.61e9 | 0.19e9 | n/sr/uC | 31.9 MeV p on 0.5 mm Be, 0 deg, E_n > 27 MeV | Ledoux2021_EPJA57_257
yield_thinLi_p | 1.77e9 | 0.21e9 | n/sr/uC | 31.9 MeV p on 1.5 mm Li, 0 deg, E_n > 27 MeV | Ledoux2021_EPJA57_257
qme_peak_pLi | 29.7 |  | MeV | 7Li(p,n)7Be quasi-monoenergetic peak at 31.9 MeV protons; 49 percent of 0 deg neutrons | Ledoux2021_EPJA57_257
qme_peak_pBe | 29.5 |  | MeV | 9Be(p,n)9B quasi-monoenergetic peak at 31.9 MeV protons; 32 percent of 0 deg neutrons | Ledoux2021_EPJA57_257
electronic_time_resolution | 80e-12 |  | s | ORTEC 462 time calibrator, commissioning run | Ledoux2021_EPJA57_257
measured_time_resolution | 1e-9 |  | s | gamma peak sigma, EJ309 detector at 15.7 m | Ledoux2021_EPJA57_257
energy_resolution_30MeV | 0.4 |  | MeV FWHM | L = 15.74 m, EJ309, 1 ns timing | Ledoux2021_EPJA57_257

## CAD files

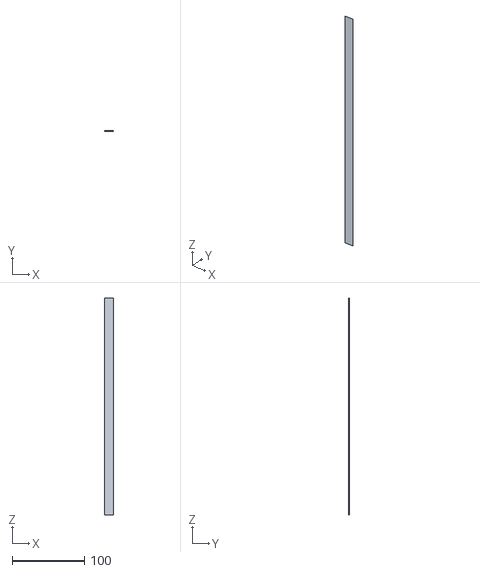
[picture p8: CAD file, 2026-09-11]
vessel_design/out/glue_bond_rod_to_foil.stl
12.0 x 0.03 x 300.0

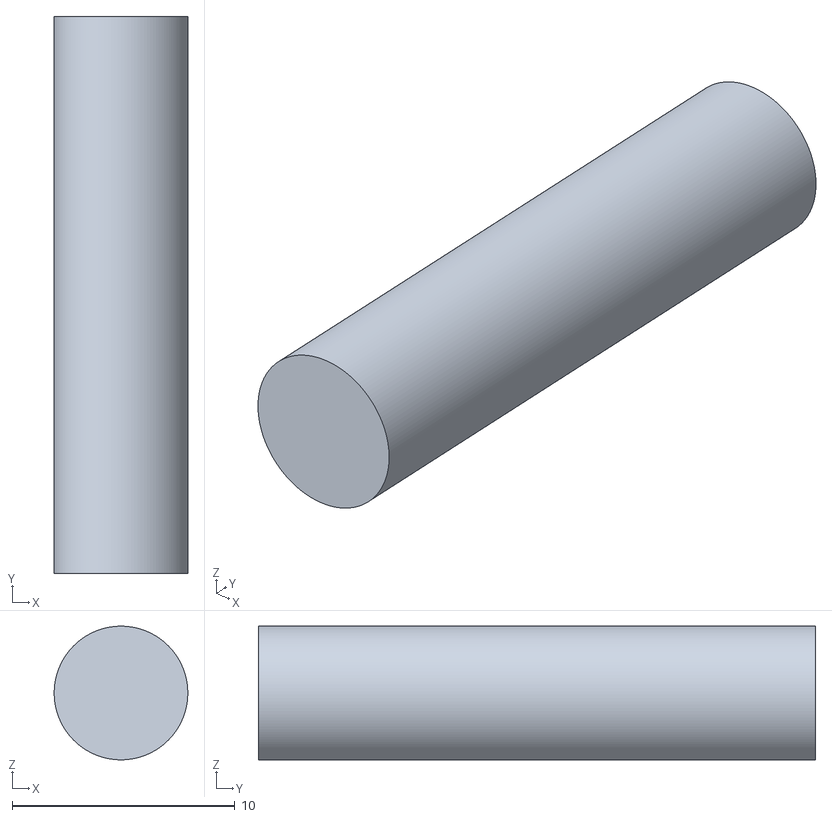
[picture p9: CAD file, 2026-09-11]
vessel_design/out/fill_port.stl
6.00 x 25.0 x 6.00

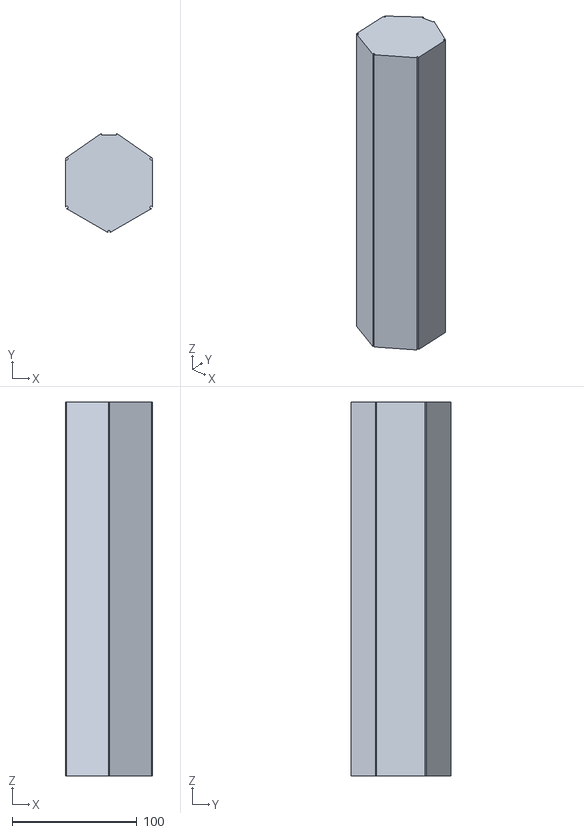
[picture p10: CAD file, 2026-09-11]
vessel_design/out/he3_gas_volume.stl
69.5 x 79.8 x 300.0

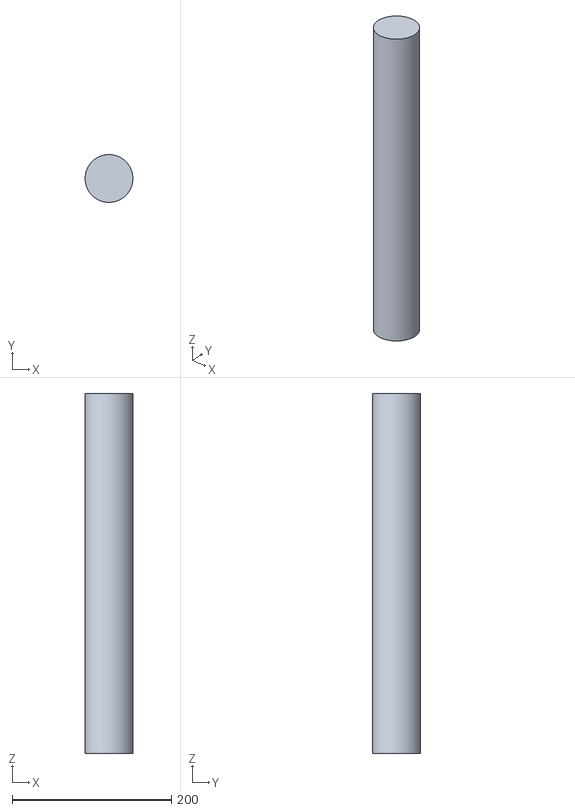
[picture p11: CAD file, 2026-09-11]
vessel_design/out/beam_envelope.stl
60.0 x 60.0 x 452.0

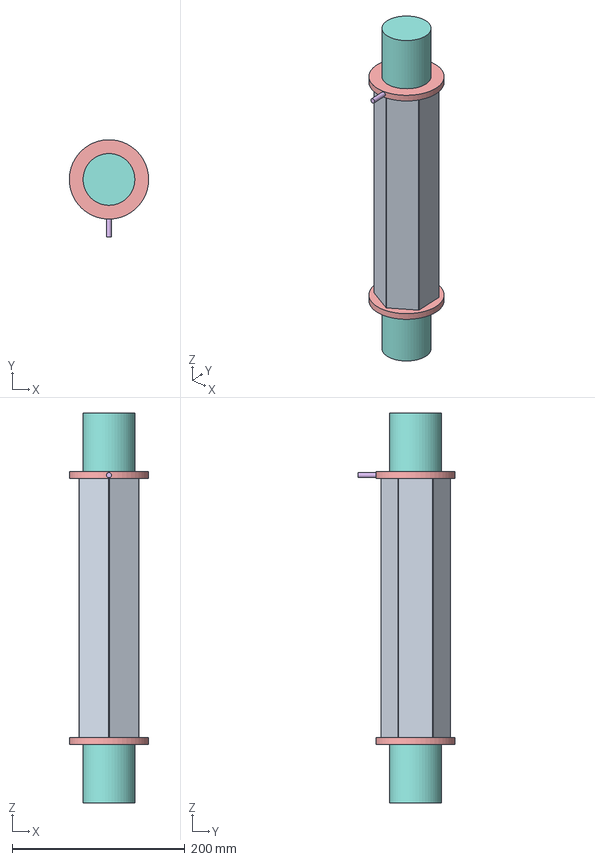
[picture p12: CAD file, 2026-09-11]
vessel_design/out/he3_mylar_vessel_with_volumes.step
91.9 x 113.0 x 452.0 mm

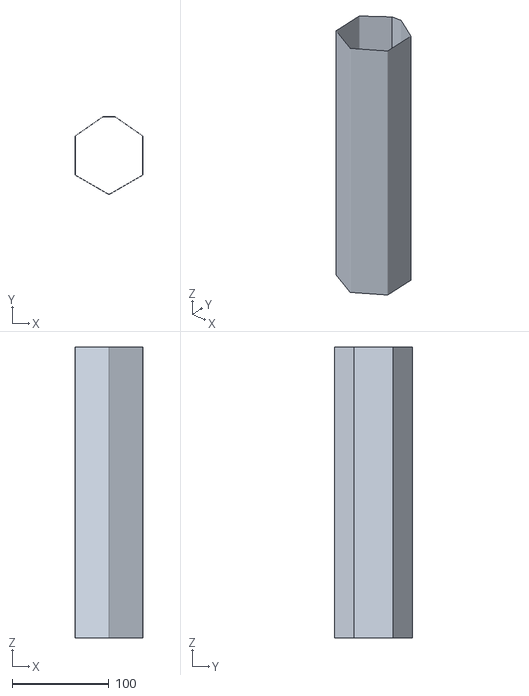
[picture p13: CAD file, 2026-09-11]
vessel_design/out/mylar_skin.stl
69.9 x 80.4 x 300.0

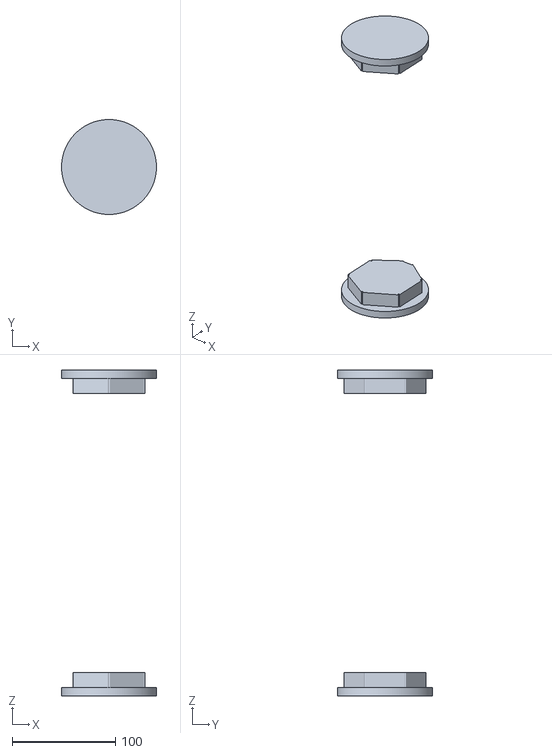
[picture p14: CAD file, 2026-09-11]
vessel_design/out/endcaps_TBD.stl
92.0 x 92.0 x 316.0

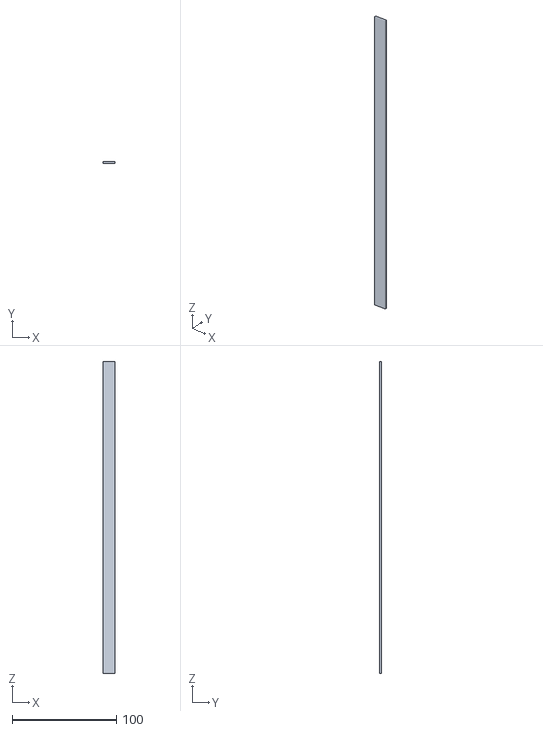
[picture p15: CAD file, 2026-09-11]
vessel_design/out/carbon_rod_flat.stl
12.0 x 1.50 x 300.0

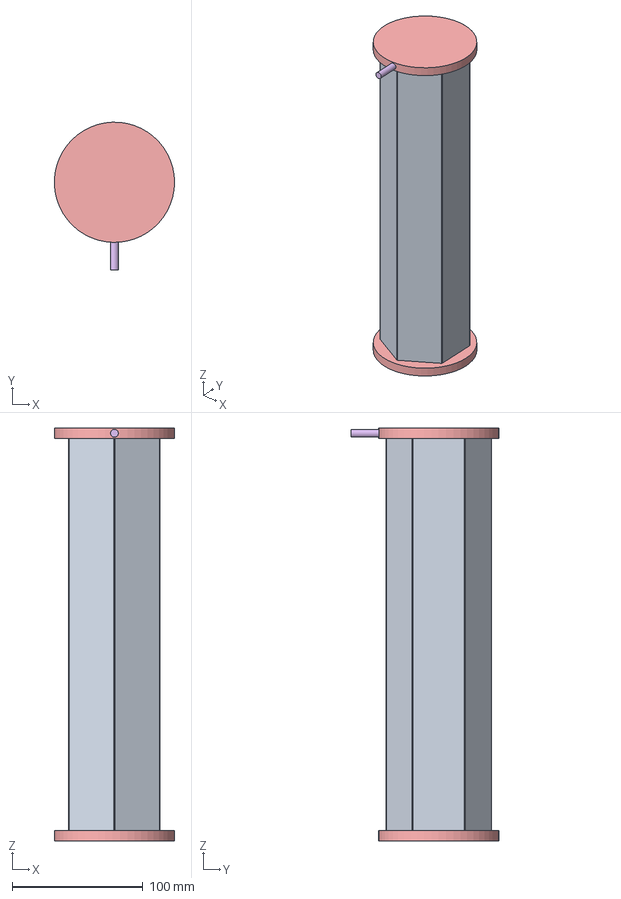
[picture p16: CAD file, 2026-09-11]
vessel_design/out/he3_mylar_vessel.step
91.9 x 113.0 x 316.0 mm

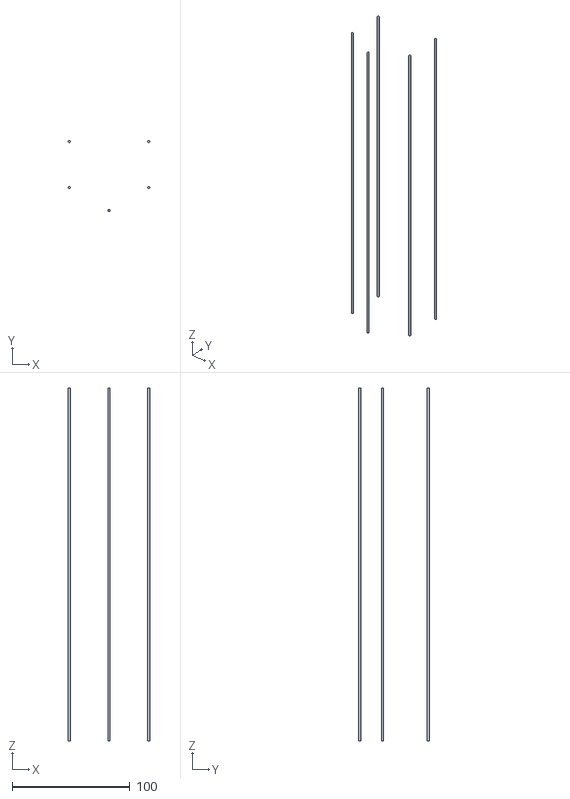
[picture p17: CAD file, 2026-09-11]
vessel_design/out/carbon_rods_round.stl
69.5 x 60.5 x 300.0

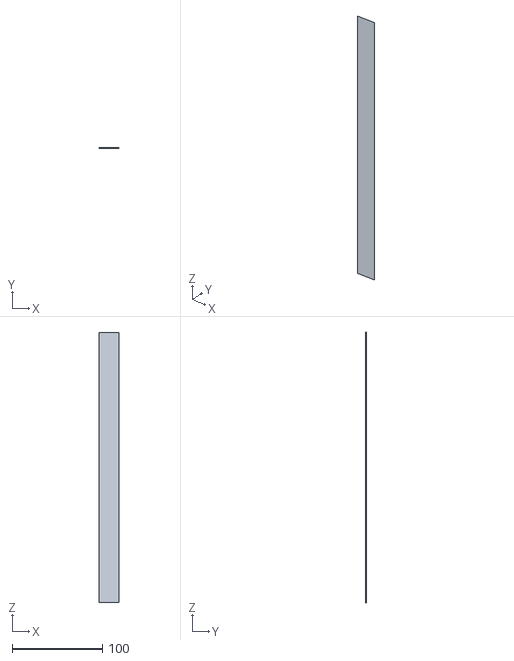
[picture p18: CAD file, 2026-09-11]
vessel_design/out/mylar_seam_overlap.stl
22.0 x 0.2 x 300.0

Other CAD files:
vessel_design/out/glue_bond_foil_to_foil.stl
vessel_design/out/he3_mylar_vessel.FCStd

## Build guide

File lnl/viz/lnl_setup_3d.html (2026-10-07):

# LNL: the MX17 arms around a lithium target, to scale

A ~1 MeV proton beam from AN2000 or CN on a sub-micron lithium film in a thin carbon-fibre chamber, with the four n_TOF arms at their as-built spacing. The other two tabs show the spectrometers that already ran this reaction, at the same scale. Everything is in centimetres. Drag to orbit, scroll to zoom. The events are illustrative draws from the same toy as lnl/lnl_rates.py.

MX17 at LNL4 Micromegas arms at 20.4 cm · Ø5 cm CFRP chamber LNL spectrometer 2023–244 plastic ΔE–E clovers at 12.5 cm · AN2000 ATOMKI 20165 telescopes + MWPC · Ø7 cm CFRP tube

Isometric Down the beam Side Zoom to target

## MX17 at LNL

### Beam and target, seen down the beam

### Run

Machine

Proton energy at the film

Target film

Show the trigger stack (SiPM walls, plastics, LS)

### Events (illustrative)

X17 pair IPC pair Cosmic μ Clear

X17 from ⁸Be* at rest, m = 16.7 MeV; IPC from the M1 virtual-photon spectrum (dN/dln M ∝ k³); cosmics cos²θ from above. A pair "counts" when its two leptons land in two different Micromegas.

### Numbers (4π, before any detector)

Yields from lnl_rates.py: Zahnow 1995 σ (EXFOR A0639) split into the two 1⁺ resonances + direct capture, PSTAR stopping. X17 at the ATOMKI ratio R = 5.8×10⁻⁶ of γ₀. IPC with the Born α (3.5–4.4×10⁻³).

Sources: MX17 arm geometry from MX17_Full_Geant SimConfig.hh (MM faces 20.40 / 20.45 cm, active 39.9 × 36.0 cm, pinwheel shifts; SiPM wall 11 cm behind the mylar; 20 × 30 × 2 cm plastics; LS slabs 45 × 45 cm). LNL clovers: Góngora-Servín et al., APPB Supp 18, 2-A13 (2025): four 2 × 2 clovers of 10 × 5 × 5 cm EJ-200 E blocks behind 20-bar ΔE layers, 12.5–13 cm from the target, at 30°, 165°, 240°, 315°. ATOMKI: Gulyás et al., NIM A 808, 21 (2016): 24 cm carbon-fibre tube, r = 3.5 cm, 0.8 mm wall; target on a 50 × 5 mm, 10 µm Al strip; Ta Faraday cup 15 cm behind; ΔE 38 × 45 × 1 mm and E 78 × 60 × 70 mm at 0°, 60°, 120°, 180°, 270°. Telescope radii are read off their Fig. 2, so they are approximate. Machines: LNL "Beams available AN2000–CN" and the 2026 CN paper (arXiv:2605.12005). Everything else: x17_facility_search/lnl/.

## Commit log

2026-09-11 Initial commit: X17 facility search project
    Vessel design (He3/mylar cell CAD + viewer), GANIL NFS beam data/refs,
    He3 material budget script, and planning docs.
    Claude-Session: https://claude.ai/code/session_011krY41JR8kFz97rSFaZ4tE
    [beam_envelope.stl, carbon_rod_flat.stl, carbon_rods_round.stl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]
2026-10-01 ILL feasibility: the thermal X17 search on a reactor cold beam
    A study next to ganil_nfs/: could the n_TOF apparatus run at the ILL, and
    what do our own n_TOF thermal results say it would see?
    - FACILITY.md: reactor cycles and power, PF1B / FIPPS beams, EBTA proposal
    route, tritium, theory context (Viviani et al.), sources.
    - POLARISED.md: polarised n + polarised 3He. (n,p) and E0 are singlet-only,
    (n,gamma) and M1 triplet-only, so spin selects the entrance channel. Covers
    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
    [he3_absorption_length.csv, polarised.csv, rate_scan.csv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]
2026-10-01 ILL: simulation handoff, beam and cell sizing, 3D beam view
    Prepares the first lxplus Geant4 campaign for the unpolarised PF1B search.
    - HANDOFF_SIM.md: drop the 500 bar capsule; scan pressure x wall x radius
    (1/2/3 bar, 12 um mylar vs Kapton pressure wall, R 40/100 mm), each cell
    long enough to stop 99.5 % of the beam and placed so its (n,gamma)
    production is centred in the Micromegas. Realistic H113 beam (measured
    spectrum, 6 x 20 cm exit, lambda-dependent divergence, analytic defining
    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
    [beam_profile_h.csv, beam_spot.csv, cell_depth.csv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]
2026-10-02 ILL: Geant4 feasibility answer from the lxplus campaign
    The G1-G6 cell scan (S1, C1, C1w, C1g, K1, S1p, S1s) answers whether X17 is
    measurable at the ILL: yes with ~200 ps per-arm timing and a cosmic veto
    (3 sigma reach X17/IPC(M1) ~ 0.85-1.3e-2 per 50-day cycle), no with the
    current 0.5 ns timing and no veto (~5e-2, cosmic-limited). Lepton
    scattering is not the limit.
    - FEASIBILITY_SIM.md: the write-up; SIM_STATUS.md: the run log.
    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
    [contract_ladders.csv, esum.csv, rate_scan.csv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]
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2026-10-02 trigger_scint: acceptance vs cost of fixing the trigger scintillators
    Facility-independent study of the MX17 trigger acceptance, from new Geant4
    runs on lxplus (T0 as built with all 20 SiPM bars, T1 one oversized
    78x120x10 cm plastic per arm; 1M X17 + 1M IPC M1 each, G1 cell) plus a
    photon ray-trace and a budgetary cost model.
    - X17 acceptance: n_TOF as built 2.3 %; 70x70x2 cm plastics 14.0 %
    (x6, ~80 kEUR); LS working only 1.2 % alone, 4.3 % OR'd with the plastics.
    - The SiPM wall, not the Micromegas, caps the acceptance (MM 27.6 %,
    MM + 20 bars 16.6 %); reading all 20 bars is worth x1.4.
    - 4-5 cm slabs give x7.7 on the ILL Esum > 13 MeV analysis (~90 kEUR in
    polystyrene, ~136 kEUR P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
    [acc_vs_cost.csv, acc_vs_length.csv, acc_vs_width.csv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]
2026-10-02 he4_bag: He flight tube against air 14N, and a foil skin against 3He leaks
    Analytic study, calibrated on the ILL Geant4 campaign, of whether a 4He
    balloon around the 3He target removes the air 14N background, plus the
    3He leak rate of the cell.
    - 4He captures no neutrons. ~90 % of the air 14N(n,g) is the direct beam
    in the 30 cm aperture -> Be-window path: 2.54e-4/n analytic vs 2.5e-4
    Geant4 V0. A He flight tube (>= 99 % He) cuts it x100.
    - A balloon around the target buys ~20 % less lepton scattering (< 2 % in
    reach). It makes the 3He problem worse: 3He leaks out just as fast, and
    4He floods in x90 faster than air.
    - Bare 12 um mylar (G1) loses ~0.45 L/day of 3He (tau 3.4 d, ~22 L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
    [he4_bag.neutrons.csv, he4_bag.permeation.csv, he4_flush_bif1.csv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]
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2026-10-02 trigger_scint: big-slab background study in progress (bkg_reach, TB campaign)
    Background model for large trigger slabs at a reactor: slab singles, trigger
    rates, in-gate pile-up and an air-capture scale on top of
    ill/sim_feasibility. As-built results only so far; the TB Geant4 runs for
    70x70x2, 75x75x5 and 75x75x5 with 6LiF/B4C wraps are still on lxplus.
    STATUS.md has the handoff.
    [bkg_budget_timing_10ns.csv, bkg_budget_timing_50ns.csv, bkg_rates.csv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]
2026-10-02 trigger_scint: restart TB background pipeline, P2 results, handoff
    Released P5_C1w reductions at 40 GB, dropped 4 truncated raw files
    (partial merge, merge_partial.sh), restarted drivers on lxplus926.
    Added asbuilt/P2 bkg_reach JSONs and figures; P2 reach matches as built
    at Esum > 13 MeV as expected. HANDOFF.md records the resume point.
    [bkg_budget_timing_10ns.csv, bkg_budget_timing_10ns_air0.csv, bkg_budget_timing_50ns.csv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]
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2026-10-02 he4_bag: choosing the Al-foil skin (metal, gauge, scattering budget, strength)
    Follow-up on the 1 bar cell skin, analytic (he4_bag.py §6):
    - The foil sits at R 40 mm, outside the beam (r99 12.9 mm): ~1e-8
    captures/n. The in-beam Al that drives accidentals is the 8 mm end caps.
    - Al is the right barrier metal; only Be is better and can't be wrapped.
    - 6-7 um converter foil on 12 um PET is enough: pinholes matter only at
    ~1/mm^2. Order PET/Al without the PE sealant layer.
    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
    [chord_budget.csv, chord_ladder.csv, foil_gauge.csv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]
2026-10-06 ILL: conservative reach (n_TOF timing, per-arm trigger, DREAM live time), MM segment cut, end-cap study
    conservative.py re-runs the G1 reach with 5 ns SiPM-wall timing, a per-arm
    coincidence trigger and DREAM live time; seg_reduce.py adds per-arm Micromegas
    segment fits so a pointing cut (and a collinearity veto) can be applied.
    Results so far in FEASIBILITY_SIM §10: 5.3e-2 -> 1.6-1.7e-2 with 2-5 deg
    segments, ~1.0-1.1e-2 with the Al end cap removed. Collinearity grid and
    CFRP / 6LiF-lined end-cap sims running on condor (HANDOFF.md).
    [ladder_5_40.csv, noseg_G1.csv, seg_10_100_0.csv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]
2026-10-07 ILL: collinearity veto replaces the ceiling panel at ≤3° MM segments
    - FEASIBILITY_SIM §10: collinearity grid (segs 2/3/5°, α 0–30°, panel vs
    none, end cap kept/off); 12 CSVs in sim/analysis_v3/cons/
    - ring_chain.sh: accounting reduce needs ~12 GB for C1w files → 14000 MB
    - HANDOFF: ring end-cap reduces running (4399502/4), then merge + reach
    [coll_2_25_0_c0.csv, coll_2_25_0_c10.csv, coll_2_25_0_c20.csv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]
2026-10-07 ILL: CFRP vs LiF end cap — CFRP 1.2e-2 with no panel, LiF no gain; n_TOF hardware slide
    [base_3_30.csv, base_3_30_np.csv, ringCFRP_3_30.csv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]
2026-10-07 ILL: what limits the reach — accidentals are Be window + air only; budget mode, biased-only estimator, Esum scan
    conservative.py: --budget (drop capture sources / zero background classes),
    --biased-only (biased volumes from C1w alone), --ecut. FEASIBILITY_SIM §11;
    corrects the §10 LiF and MC-statistics claims. New slide 'What blocks us'.
    [bo_base.csv, bo_ringCFRP.csv, bo_ringLiF.csv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]
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2026-10-07 ILL: MM occupancy loss applies to every class (ACC, COS, WALL too), not just the signal side
    The old fits (signal-side only) are kept on EOS as *_occsig.csv. The CFRP walls and
    budget fits are resubmitted with the fix; the tube-variant fits will use it.
2026-10-07 ILL §13: He flight tube + thin window variants, rate walls (real fits), occupancy-fix refits; deck slides window + walls
    Tube + Be 0.25 mm / mylar window: trigger 249 -> 8-23 Hz, MM occupancy 0.24 -> 0.11,
    reach 5.3-5.75e-3 at ~6e10 n/s (x3.2-3.5 from 8Be, was x7.4). Walls left: MM
    occupancy + DREAM; IPC floor at PF1B max 2.1e-3 (x1.3).
    [bo_ringCFRP.csv, bo_ringCFRP_occsig.csv, bo_tubeBe.csv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]
2026-10-08 LNL: Geant4 campaign L1-L6 + big plastics + 20-bar readout; data-like analysis (sim/lnl_geant.py) and FEASIBILITY_SIM.md
    As built: ~15 d (counting) / 22 d (fit) to 3 sigma at R(ATOMKI), 1 uA, once cosmics are
    killed by 3-deg MM segments or a 0.3 ns TOF veto; E_sum separates the 15 MeV IPC.
    Big plastics 75x75x5: ~1.2-1.6 d. Cosmics are the only dangerous background.
    Claude-Session: https://claude.ai/code/session_015EmnVDtzczAiRJZ987HZk4
    [acceptance_geant.csv, cosmics_asbuilt.csv, cosmics_asbuilt_noLS.csv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]
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2026-10-09 LNL deck: slide 13 only the current bar position with the optimum; slide 16 one week of pseudo-data and how the significance is computed
    - plastics_scatter.py: size slide keeps only R = 41 cm (SiPM wall stays in the leg), vertical line at the
    77.5 cm minimum; scatter-week slide replaces the per-day stacked plots: pseudo-data per week / 4°, excess over
    the IPC (truth vs measured X17), Z vs time for counting / IPC-norm-free fit / M1-E1-g1-free fit / 2 % shape
    - sim/lnl_week.py: week.csv, week_z.csv, scatter_week.png from stacked.csv and reach_geant.csv
    - FEASIBILITY_SIM.md section 11 (S/B ~ 7 %: the IPC shape systematic caps Z), section 8 item 9, README, HANDOFF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
    [scatter_week.csv, week.csv, week_z.csv]
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2026-10-14 LNL §16: 2D maps of the θ×|y|×E_sum fit and the impostor test (a background error copying the X17 angle spectrum: 100 % in 1D, 13–24 % in 3D); 3 pitch slides
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2026-10-16 Budget: comment buttons (general / missing item / per item, name remembered) with an Apps Script backend; Self-sufficient default
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2026-10-19 GANIL/NFS: spectrum fold (gate 2), Geant4 N1-N3 runs, first reach (FEASIBILITY_SIM.md)
    Below 2.75 MeV: rho(3 sigma) = 2.2e-2 in 14 d with big plastics, 15x above ATOMKI 4He.
    All E_n to 25 MeV with TOF: 2.5e-3, assuming X17/IPC is constant in E* and the beam
    background is small (the 0.28 s beam sample can't constrain it). Fixes the fold's full
    table being overwritten by the figure CSV (now fold_table.csv); reach histograms are
    built once per window (10+ min -> 3 s).
2026-10-19 GANIL/NFS: beam background pipeline for the forced Geant4 runs
    nfs_beam_reduce/merge.py: per-arm scintillator time clusters (leg, energies and MM segment per
    cluster), event weights, forced-collision checks; same-event coincident pairs + singles.
    nfs_reach.py: beam events binned by measured TOF (folded into the bunch period), event weights,
    accidental pairs of singles within an E_n bin (|dt| < 5 ns), --beam N4|N3c|N3.
    nfs_pipe.sh: breduce/bmerge; submit_nfs.py: --reduce-in-job.
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2026-10-21 LNL lithium target study: why LNL 2023-24 stalled (19F in LiF at 1.03 MeV, hot strip targets) and the MX17 target spec
    target_model.py (19F/11B/7Li yields through layered targets, foil heat, Li diffusion and evaporation,
    carbon build-up, H fluence), target_rates.py (MX17 rates from Geant4 L8 singles; LNL-like toy),
    target_fit_bias.py (Fisher bias of the 3D fit for diffusion, hydration, carbon, boron), slide note
    lnl-lithium-target, TARGET_STUDY.md; dashboard LNL entry and log.
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2026-10-26 LNL: the photographed beam line around the arms (TARGET_OPTIONS §18, opt_beamline.py, 3D page lnl_beamline_3d.html): target at the detector centre; cup is at the photo's left end (audit A2 corrected)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
2026-10-26 LNL: window is Ø20 mm 200–300 µm diamond in Ti rings (B1 decided; design page variant t45_ti20, stress text corrected); beam-line page: cup glued straight onto the tube (out of view, steel or CFRP; C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
2026-10-27 lnl: Pierfrancesco's CAD sketch analysed (TARGET_OPTIONS §19, opt_sketch.py) and a 'His sketch' tab on the target page
    Four loose bodies: a pointed 0.2 mm ogive Ø50x63 (the target), a solid R25 hemisphere,
    a Ø41x1 tube with Li Ø40x20 µm. Traced: Cu ogive 2.9 % X0/lepton vs 4.7 % for the L10
    hemisphere and 0.6 % for our window; clean in Be/Al. New: the spot spills onto the
    65° flank, so at 1.03 MeV 42 % of protons cross 441 keV (17.64 line 69 % of γ0).
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2026-10-29 he3_target: engineering feasibility plan for the ³He target at a fast-neutron beam (Birmingham case)
    Code-sized vessels, real gas, PED/PER class, stored energy, leak budget, tritium, days interpolated from the
    Geant4 rows; baseline 30 bar R 4 Al-lined CFRP (62 L, ~7 d est), closed cryopump gas loop, ³He loan, what to
    simulate next. READMEs, TARGET_GEANT risk pointer, dashboard EXTRA/LOG, HANDOFF.
2026-10-29 daq_trigger: DREAM TCM busy output (LEMO to fit) replaces the fixed busy lock; V1730 trigger facts from UM2792; option C′ (one V1730S per arm, no FPGA); interactive page mx17-daq-trigger (page/, depl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
2026-11-10 INFN statement check (interim): LNL as-built reach was an MC artefact (shapes_nd.py, reference fit MC-safe: Cu ogive 6-11 d, Al+Cu liner 4.5-8.5 d at 1 uA); pulsed vs continuous beam; programme; beam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
2026-11-10 LNL beam current corrected to 1 uA (beam sheet) and pulsed beam reworded as a cross-check across the main deck, viewer, READMEs and surveys; Birmingham decks, he3 deck and dashboard labelled statisti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
2026-11-11 LNL target: decks, target page and budget brought in line with the 11 Nov buildability review
    review_data.py as the shared verdict/cap/Li data; dated 'where this stands' slides in all seven decks;
    compare deck with the flat Al end cap first, live vs dropped, three day columns, Li and baseline slides;
    shapes deck Mo K occupancy corrected; lithium-target deck's Li2O spec superseded; target page Review tab
    (export_review_viz.py) with status banners on older tabs; budget end caps + Li metal + fast valve;
    thin-Li reach rows; L14 (cap) lxplus scripts; pointer notes; HANDOFF
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
